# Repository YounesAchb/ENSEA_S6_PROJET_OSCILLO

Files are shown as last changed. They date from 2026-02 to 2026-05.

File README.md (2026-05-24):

# ENSEA S6 — Projet Oscilloscope Portable Connecté

Ce dépôt contient l'intégralité des sources (conception matérielle KiCad, firmware STM32 et application Java Android) du projet de fin de S6 réalisé à l'ENSEA. 

## 👥 Étudiants concernés
* **Yassine JABOU**
* **Younes ACHBAD**
* **Gabriel BOUDOUX D'HAUTEFEUILLE**
* **Gökay OZDEN**

---

## 📝 Abstract & Contexte de Fin de Projet
Le but de ce projet est de concevoir un système embarqué autonome agissant comme un oscilloscope de précision déporté. L'écosystème est divisé en deux parties principales :
1. **Un boîtier d'acquisition autonome :** Reçoit le signal analogique, adapte son amplitude, le numérise via un STM32L476RG et transmet les trames via un module Bluetooth HC-05.
2. **Une interface utilisateur (Display) :** Une application Android native développée en Java permettant la visualisation en temps réel, le contrôle des calibres, les mesures par curseurs et le traitement fréquentiel (FFT).

⚠️ **Statut Réel du Projet (Post-Soutenance) :** Suite à un retard de livraison critique de notre fournisseur sur le composant analogique central (l'amplificateur à gain programmable PGA849), le PCB final n'a pas pu être assemblé et soudé à temps pour les tests physiques. 
Cependant, l'ensemble du projet a été validé avec succès par une **approche de virtualisation et de simulation** :
* **Hardware :** PCB double couche entièrement routé et validé par DRC sous KiCad.
* **Firmware C :** 100% fonctionnel, validé sur carte Nucleo en simulant l'absence du PGA.
* **Application Android :** 100% fonctionnelle, dotée d'un banc de simulation générant des signaux virtuels cohérents permettant de valider l'interface utilisateur, le protocole de communication et les algorithmes de traitement (FFT, curseurs).

---

## 🛠 Spécifications du Projet

### 1. Performances & Objectifs Communs
* **Nombre d'entrées :** 2 voies (1 voie implémentée et validée sur cette version).
* **Bande passante visée :** 10 Hz - 50 kHz.
* **Résolution d'acquisition :** 12 bits.
* **Échantillonnage :** 10 kHz fixe, rythmé de manière matérielle par Timer.
* **Points par capture :** Buffer circulaire de 1024 points (gestion par demi-tableaux de 512 points).
* **Communication :** Liaison Bluetooth SPP (Standard Serial Port Profile) à 115200 bauds.
* **Gestion de l'énergie :** Objectif d'autonomie de 6 heures sur piles (sélection de composants Low-Power).

### 2. Architecture Matérielle (Hardware)

Le routage a été optimisé sur un PCB compact double couche. La conception repose sur une séparation stricte des masses et une cascade d'alimentation spécifique pour préserver la propreté du signal de référence ($V_{ref}$) de l'ADC.

#### Schéma Bloc de l'Architecture Électronique
```mermaid
graph TD
    classDef power fill:#2d3436,stroke:#deff9a,stroke-width:2px,color:#fff;
    classDef analog fill:#d63031,stroke:#fff,stroke-width:2px,color:#fff;
    classDef digital fill:#0984e3,stroke:#fff,stroke-width:2px,color:#fff;
    classDef com fill:#00b894,stroke:#fff,stroke-width:2px,color:#fff;

    subgraph Alimentation & Énergie
        Piles((Piles 3xAA)) -->|BAT_PLUS| Switch[Interrupteur + Diode Schottky]
        Switch -->|Vin| LDO3[LDO 3.3V: AP2112K]:::power
        Switch -->|Vin| LDO5[LDO 5V: MCP1826S]:::power
        LDO5 -->|Sortie 5V| Traco[DC/DC Symétrique: Traco TSM]:::power
        Traco -->|+15V / -15V| PGA
    end

    subgraph Chaîne Analogique
        BNC((BNC Verticale 50Ω)) -->|Signal Brut| PGA[Ampli de précision: PGA849]:::analog
        PGA -->|Signal Conditionné| Clamping[Diode de protection: BAT54S]:::analog
        Clamping -->|Entrée Analogique PA0| MCU
    end

    subgraph Traitement & Communication
        LDO3 -->|V3.3_DIG| MCU[MCU: STM32L476RG]:::digital
        MCU -->|Sélection Calibre 3-bits| PGA
        LDO5 -->|5V BT| BT[Module Bluetooth: HC-05]:::com
        MCU <-->|UART 115200 bauds| BT
        BT -.->|Sans-fil SPP| Android((App Android Java)):::com
    end

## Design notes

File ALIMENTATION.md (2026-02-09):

**Systeme d’alimentation** 

**Batterie Renata Li-Po 500mAh :**  source d'énergie. Compacte et fiable, elle offre environ 7 heures d'autonomie.  
**Régulateur LDO AP2112K (3,3V) :** convertit la tension variable de la batterie en un 3,3V stable pour le STM32. Il est choisi pour son faible bruit, indispensable pour ne pas perturber les mesures de l'oscilloscope.  
**Chargeur MCP73831 :** C'est le "cerveau" de la recharge. Il gère le cycle de charge sécurisé de la batterie (CC/CV) pour éviter toute surchauffe.  
**Connecteur USB-C GCT (USB4110) :** port d'entrée pour l'énergie. Il est robuste mécaniquement et possède des pins accessibles pour une soudure manuelle facilitée.  
**Boîtier JST PHR-2 femelle :** C'est la partie en plastique qui se fixe au bout des fils de ta batterie pour permettre un branchement propre sur la carte.  
**Commutateur ON/OFF Würth :** Un interrupteur physique robuste pour allumer ou éteindre ton appareil sans avoir à débrancher la batterie.  
**Transistor BSS84 (MOSFET P) :** Il assure une protection électronique contre l'inversion de polarité. Si la batterie est branchée à l'envers, il coupe instantanément le circuit sans perte de tension.  
**Perle de ferrite Murata :** Elle agit comme un filtre "anti-parasites" pour isoler l'alimentation de la partie mesure (ADC) des bruits générés par le Bluetooth.  
**L'Embase JST PH mâle (B2B-PH-K-S) :** C'est le connecteur que l’on soude sur le PCB. Sans lui, on ne peut pas brancher ton boîtier PHR-2.  
**Les Contacts à sertir JST (SPH-002T-P0.5L) :** Ce sont les petites broches métalliques qu'il faut fixer au bout des fils de la batterie avant de les glisser dans le boîtier PHR-2.

COMPOSANTS QUE JE N’AI PAS RAJOUTÉ AU SOURCING   
**1.Résistances de configuration**

* **2x Résistances de 5,1 kΩ :** À placer sur les pins CC1 et CC2 du port USB-C. Sans elles, les chargeurs modernes (smartphone/PC) ne délivreront aucun courant.  
* **1x Résistance de 2 kΩ :** À brancher sur la puce MCP73831 pour fixer le courant de charge à 500mA (recharge complète en 1h).  
* **2x Résistances de 100 kΩ :** Pour créer un "pont diviseur". Cela permet au STM32 de mesurer la tension de la batterie et d'envoyer le niveau de charge (ex: 75%) à ton smartphone et surtout faire un pont diviseur de tension pour limiter la tension de la batterie .  
* **1x Résistance de 470 Ω :** Pour limiter le courant de la LED de statut.

#### **2\. Condensateurs de stabilité**

* **2x Condensateurs de 10 µF (Céramique) :** Indispensables pour stabiliser l'entrée et la sortie du chargeur MCP73831.  
* **2x Condensateurs de 1 µF (Céramique) :** Nécessaires pour que le régulateur AP2112K fonctionne sans osciller.  
* **Plusieurs condensateurs de 100 nF :** À placer au plus près de chaque puce (STM32, AOP) pour filtrer les micro-parasites.

#### **3\. Indicateur visuel**

* **1x LED (Rouge ou Verte) :** Indispensable pour savoir visuellement si la batterie est en cours de chargement quand tu branches l'USB.

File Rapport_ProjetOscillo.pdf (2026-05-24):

ÉCOLE NATIONALE SUPÉRIEURE DE

L'ÉLECTRONIQUE ET DE SES APPLICATIONS

RAPPORT DE PROJET — SEMESTRE 6

# OSCILLOSCOPE PORTABLE CONNECTÉ

2025-2026

Étudiants :

JABOU Yassine · ACHBAD Younes BOUDOUX d'HAUTEFEUILLE Gabriel · OZDEN Gökay

Oscilloscope Portable Connecté — ENSEA S6 2025–2026

JABOU · ACHBAD · BOUDOUX d'HAUTEFEUILLE · OZDEN | 2

### Remerciements

Nous remercions nos encadrants de l'ENSEA pour leur accompagnement tout au long du
semestre, | et | particulièrement | pour | leur | compréhension | lors | des | difficultés
d'approvisionnement que nous avons rencontrées. Leurs retours lors des séances de suivi ont été déterminants pour prioriser nos efforts sur ce qui était réalisable dans les délais. Merci également au laboratoire de l'école pour l'accès au matériel de mesure et aux postes de soudure du FabLab

### Résumé

Ce rapport présente la conception et le développement d'un oscilloscope portable connecté, réalisé dans le cadre du projet de semestre 6 à l'ENSEA. Le projet s'articule autour d'un boîtier d'acquisition matériel (PCB sur STM32L476RG) et d'une application Android Java pour la visualisation des signaux via Bluetooth.
Note préliminaire sur l'état d'avancement : un retard critique de livraison de composants chez notre fournisseur principal (Mouser) a empêché l'assemblage final du PCB dans les délais du projet. Cette contrainte, indépendante de notre volonté, n'a pas remis en cause la conception — le routage KiCad est 100 % finalisé et validé (DRC OK) — mais elle a conduit à orienter la validation vers une approche simulation logicielle. L'ensemble du système est « ready-to-plug » : dès réception et soudure des composants manquants, la chaîne complète peut être mise en service sans modification de conception.
Ce qui a été pleinement développé et validé :
- PCB double couche ~24 × 95 mm : schéma complet, routage terminé, DRC validé, carte reçue du fabricant
- Firmware STM32 en C (HAL) : acquisition ADC 12 bits, DMA circulaire double buffer à 10 kHz, driver PGA849, protocole Bluetooth 0xAA/0x55, machine à états
- Application Android Java : affichage temps réel, trigger réglable, FFT 512 points (fenêtre de Hann), curseurs ΔT/ΔV, mesures automatiques, mode simulation complet
- Validation protocole complète : liaison UART/Bluetooth testée, endianness corrigé, trames vérifiées

Abstract

This report presents the design and development of a portable connected oscilloscope, completed as part of the semester 6 project at ENSEA. The system consists of a hardware acquisition board (PCB around STM32L476RG) and a Java Android application for wireless signal visualization over Bluetooth.
A critical component delivery delay prevented final PCB assembly within the project timeline. The KiCad routing is fully complete and DRC-validated; the system is ready-to-plug pending soldering. All software components — STM32 firmware (C, HAL, DMA), Bluetooth protocol, and the Android application (real-time display, FFT, trigger, cursors, simulation mode) — have been fully developed and validated through software simulation and partial hardware testing.

### 1. Introduction

### 1.1 Contexte et motivation

L'oscilloscope est l'instrument de base de tout laboratoire d'électronique. Il permet de visualiser en temps réel l'évolution d'un signal, de mesurer son amplitude et sa fréquence, et de diagnostiquer le comportement d'un circuit. Les oscilloscopes de banc professionnels sont efficaces mais encombrants et coûteux — souvent hors de portée pour un usage nomade ou terrain.
Ce projet visait à concevoir une alternative compacte : un oscilloscope embarqué alimenté sur batterie, qui transmet les données à un smartphone Android via Bluetooth. Toute la puissance d'affichage et de traitement du signal est déportée sur l'application mobile, ce qui simplifie le firmware et permet une interface bien plus riche qu'un écran embarqué de quelques centimètres.

### 1.2 Cahier des charges

Les spécifications fixées en début de projet étaient les suivantes :
- 2 voies d'entrée analogiques (1 voie implémentée dans la V1)
- Bande passante : 10 Hz – 50 kHz
- 1024 points par capture en mode dual, 2048 en mode simple
- Transmission Bluetooth sans dégradation vers application Android
- Autonomie visée : 6 heures sur batterie
- Interface de visualisation complète sur smartphone

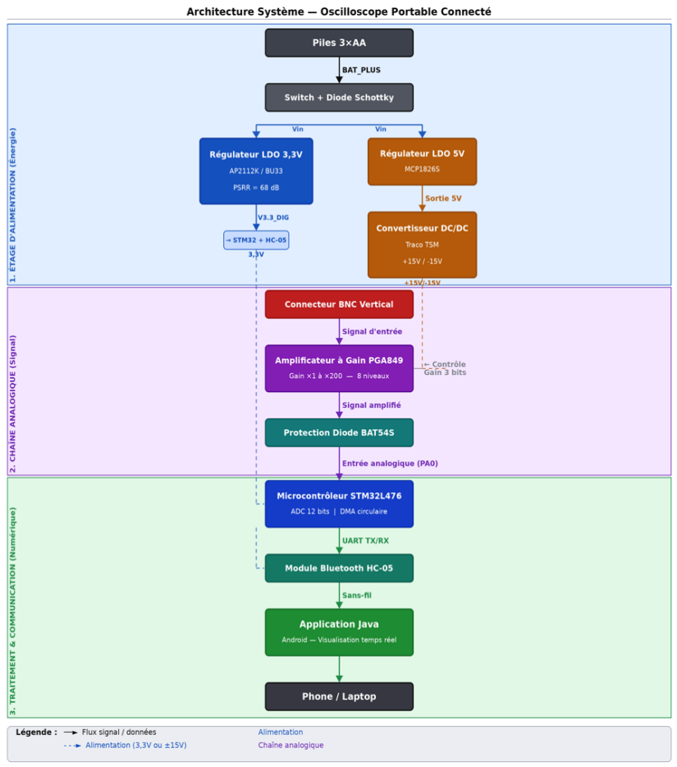
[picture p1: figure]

- Fig. 1 — Architecture globale du système : BNC → PGA849 → STM32 → HC-05 → Application Android Java.

### 1.3 Déroulement réel du projet et état final

Le projet a été conduit sur environ quatre mois, entre les contraintes académiques habituelles (cours, partiels) et les aléas propres à tout projet hardware : délais fournisseurs, itérations sur le schéma, débogage firmware. La chronologie réelle s'est articulée autour de trois phases :
1. Phase de conception (semaines 1–5) : spécifications, choix des composants, schéma KiCad, création des empreintes personnalisées (PGA849 QFN-16, TSM0515D).
2. Phase de développement logiciel (semaines 4–10) : firmware STM32 en parallèle du PCB, développement de l'application Android Java avec mode simulation.
3. Phase d'intégration (semaines 11–14) : routage PCB finalisé, DRC validé, carte envoyée en fabrication. Validation firmware + Bluetooth sur Nucleo. Assemblage PCB non finalisé (retard composants Mouser).

### 2. Présentation Générale du Projet

### 2.1 Architecture système

Le système se découpe en deux sous-ensembles communiquant sans fil :
- Le boîtier embarqué : chaîne analogique (BNC → PGA849 → ADC) + STM32 (firmware C, DMA, Bluetooth UART) + alimentation batterie.
- L'application Android Java : réception Bluetooth, décodage protocole, affichage temps réel, traitement signal (FFT, trigger, curseurs), simulation intégrée.

L'idée de déporter l'affichage sur le smartphone a été validée dès le départ. Cela évite d'intégrer un écran dans le boîtier, réduit la consommation, simplifie le firmware, et offre une interface incomparablement plus riche qu'un petit OLED.

### 2.2 Synthèse des choix techniques

Composant / Choix | Justification technique
STM32L476RG (NUCLEO) | ADC 12 bits intégré, famille L4 basse consommation, HAL documentée, familier des TPs
PGA849 (Texas Instruments) | Gain programmable 3 bits (×1 à ×200), faible bruit, piloté par 3 GPIO STM32
BU33SD5WG (ROHM, SSOP-5) | LDO 3,3 V, PSRR = 68 dB — filtre le ripple HF du Traco pour protéger l'ADC
TSM0515D (Traco Power) | Convertisseur DC/DC ±15 V isolé depuis 5 V pour alimentation symétrique PGA849
BAT54S (Schottky) | Double protection : inversion polarité batterie + clamping surtension entrée ADC
HC-05 Bluetooth SPP | UART transparent, profil SPP, simple à interfacer STM32 et Android
DMA Circulaire double buffer | Acquisition déterministe 10 kHz, zéro perte, charge CPU ≈ 0 % pendant l'ADC

Application Android Java | Interface riche (FFT, trigger, curseurs), mode simulation intégré, pas d'écran embarqué

### 3. Partie Hardware

### 3.1 État d'avancement — rappel de contexte

Les sections qui suivent décrivent la conception telle qu'elle a été réalisée. Les justifications techniques sont celles qui ont guidé les choix. Les résultats expérimentaux présentés en section 6 correspondent uniquement à ce qui a effectivement pu être testé.

### 3.2 Alimentation — Conception de la chaîne d'énergie

### 3.2.1 Contraintes et architecture

La chaîne d'alimentation est le sous-système qui a demandé le plus de réflexion, pour deux raisons :
- Le PGA849 nécessite une alimentation symétrique (±VS) pour amplifier des signaux centrés autour de 0 V sans saturation.
- L'ADC 12 bits de la STM32 a une résolution de 1 LSB = 3300/4096 ≈ 0,806 mV. La moindre perturbation haute fréquence sur la tension d'alimentation se retrouve directement dans les échantillons numérisés.

Ces deux contraintes ont conduit à une architecture cascade à deux branches, illustrée ci-dessous :

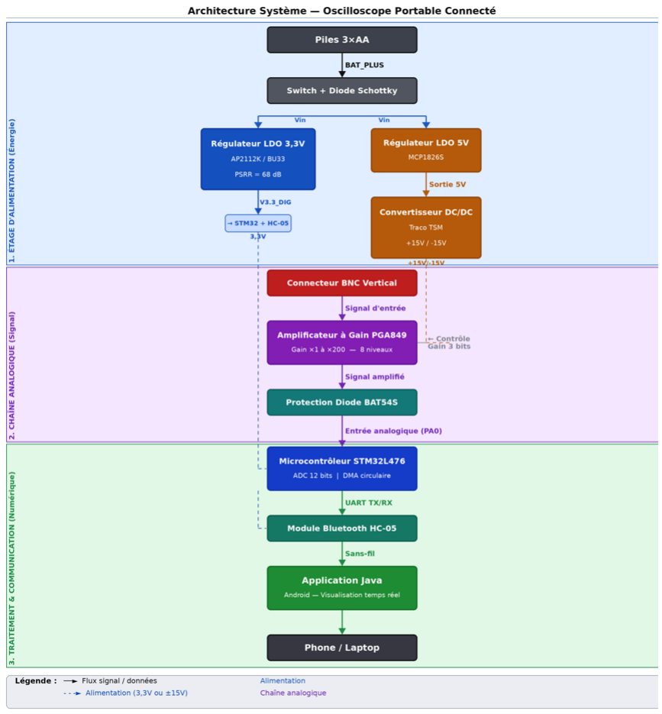
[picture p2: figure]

Fig. 1 — Architecture globale du système : BNC → PGA849 → STM32 → HC-05 → Application Android Java.

### 3.2.2 Branche 1 — Alimentation ±15 V pour le PGA849

Les piles 3×AA (4,5 V nominal) alimentent d'abord un LDO MCP1826S qui fournit un 5 V stabilisé. Ce 5 V est ensuite converti en ±15 V symétrique par le TSM0515D de Traco Power, un convertisseur DC/DC isolé à découpage.
Le TSM0515D est un module tout-intégré qui simplifie considérablement la conception : pas besoin de transformer, de contrôleur PWM, ni de bobine externe. Il génère cependant un ripple HF caractéristique des convertisseurs à découpage — ce qui impose le soin apporté à la branche 3,3 V.

### 3.2.3 Branche 2 — 3,3 V propre pour le STM32 : le rôle clé du BU33SD5WG

La branche 3,3 V est critique. Elle alimente directement le STM32 (donc son ADC) et le module Bluetooth. Pour cette branche, nous avons sélectionné le LDO BU33SD5WG de ROHM (boîtier SSOP-5, 500 mA max) à la place d'un LDO générique.
Le critère déterminant est son PSRR (Power Supply Rejection Ratio) exceptionnel de 68 dB. Ce paramètre mesure la capacité du régulateur à atténuer les perturbations présentes sur sa tension d'entrée avant qu'elles n'atteignent la sortie. En termes concrets :
PSRR = 68 dB → atténuation = 10^(68/20) ≈ 2512×
Autrement dit, un bruit de 100 mV crête sur l'entrée du BU33SD5WG (généré par le Traco) n'apparaît qu'à ~40 µV sur la tension 3,3 V fournie à l'ADC. Or à 12 bits, 1 LSB = 0,806 mV : cette perturbation résiduelle de 40 µV représente moins de 0,05 LSB, ce qui est parfaitement négligeable. Un LDO standard (PSRR typique 40 dB) aurait laissé passer ~1 mV, soit plus d'un LSB de bruit parasite.
Ce choix est donc la clé de la précision de mesure du système, et pas un détail de conception.

### 3.2.4 Protection en entrée — Diode Schottky et BAT54S

Deux protections sont intégrées en entrée du circuit :
- Diode Schottky série : protège l'ensemble du circuit contre une inversion de polarité lors de l'insertion des piles. Le seuil bas (~0,3 V) minimise la chute de tension sur la branche d'alimentation.
- BAT54S (double Schottky en boîtier SOT-23) : utilisée comme diode de clamping sur l'entrée analogique. En cas de signal d'entrée dépassant les rails d'alimentation du PGA, les diodes Schottky écrêtent la tension avant qu'elle n'atteigne l'ADC. Les diodes Schottky sont privilégiées ici pour leur faible capacité parasite, qui n'altère pas la bande passante du signal.
Composant | Référence | Rôle | Valeur clé
LDO 5 V | MCP1826S | 5 V stabilisé pour le Traco | 1 A max
DC/DC ±15 V | TSM0515D (Traco) | Alimentation symétrique PGA849 | Isolé, ±15 V / 70 mA
LDO 3,3 V | BU33SD5WG (ROHM) | 3,3 V propre STM32 + HC-05 | PSRR = 68 dB
Découplage HF | 100 nF × 10 (CMS) | Filtrage hautes fréquences | Placés au plus près des ICs
Filtrage BF | 10 µF × 3 (électro) | Stabilisation basse fréquence | Sorties régulateurs
Protection polarité | Schottky série | Inversion polarité batterie | Vf ≈ 0,3 V
Protection ADC | BAT54S | Clamping surtension entrée | Faible capacité parasite

### 3.2.5 Estimation d'autonomie

Avec 3 piles AA de 2500 mAh et une consommation totale estimée à ~400 mA (STM32 ~30 mA, PGA849 ~10 mA, HC-05 ~40 mA, TSM0515D ~100 mA équivalent avec pertes) : Autonomie estimée ≈ 2500 mAh / 400 mA ≈ 6,25 heures
Cette valeur est cohérente avec l'objectif du cahier des charges (6 heures). Elle n'a pas pu être vérifiée expérimentalement faute d'avoir assemblé le circuit complet.

### 3.3 Chaîne d'acquisition analogique

### 3.3.1 Amplificateur à gain programmable PGA849

Le PGA849 de Texas Instruments est l'élément central de la chaîne d'acquisition. Il amplifie le signal d'entrée avec un gain sélectionnable sur 8 niveaux, codés en binaire sur 3 broches logiques (A0, A1, A2) pilotées par les GPIO PA4, PA5, PA6 de la STM32.
Le signal d'entrée arrive via un connecteur BNC vertical (TE Connectivity 1478204), standard en laboratoire. La sortie du PGA attaque directement l'entrée analogique de l'ADC1 (broche PA0, canal IN5 de la STM32).
Code A2:A1:A0 | Gain | Plage d'entrée typique
000 | ×1 | > 1 V crête — signaux forts
001 | ×2 | 500 mV – 1 V
010 | ×5 | 200 – 500 mV
011 | ×10 | 100 – 200 mV
100 | ×20 | 50 – 100 mV
101 | ×50 | 20 – 50 mV
110 | ×100 | 10 – 20 mV
111 | ×200 | < 10 mV — signaux très faibles

### 3.3.2 Résolution de l'ADC

L'ADC1 de la STM32L476 est configuré en 12 bits, référence Vref = 3,3 V :

### 1 LSB = 3300 mV / 4096 ≈ 0,806 mV (gain ×1)

Au gain maximum ×200 du PGA, la résolution effective sur le signal d'entrée descend à 0,806 / 200 ≈ 4 µV/bit en théorie. En pratique, le bruit de fond du PGA849 et du câble d'entrée fixerait la résolution réelle à quelques dizaines de µV — ce qui reste excellent pour la plage de fréquences visée.

### 3.4 PCB — Conception et routage

### 3.4.1 Caractéristiques

Format double couche, dimensions ~24 × 95 mm, coins arrondis. Organisation des couches :
- F.Cu : signaux, pistes 0,25 mm minimum, composants CMS (STM32 LQFP-64, PGA849 QFN-16, Traco TSM0515D, LDO, condensateurs)
- B.Cu : plan de masse GND continu (copper fill) — isole les perturbations HF du Traco et garantit un retour de courant propre

Connectique intégrée : BNC vertical THT (entrée signal), module HC-05 (Bluetooth), connecteur SWD 5 broches J4 (SWCLK, SWDIO, NRST, GND, 3,3 V) pour programmation et debug sans démonter la carte, interrupteur glissière marche/arrêt, support piles 3×AA, 2 vis M3 pour fixation boîtier.

### 3.4.2 Règles de routage appliquées

- Isolation analogique : BNC et PGA849 regroupés, distants des zones numériques (STM32, HC-05). Le plan de masse continu B.Cu sépare physiquement les domaines.
- Découplage au plus près : les 100 nF sont placés à moins de 2 mm de chaque broche d'alimentation des ICs.
- Empreintes personnalisées : PGA849 QFN-16 et TSM0515D créées manuellement dans la librairie Empreintes.pretty — les bibliothèques standard KiCad ne les incluent pas.
- DRC validé sans erreur — la carte a été envoyée en fabrication et reçue.

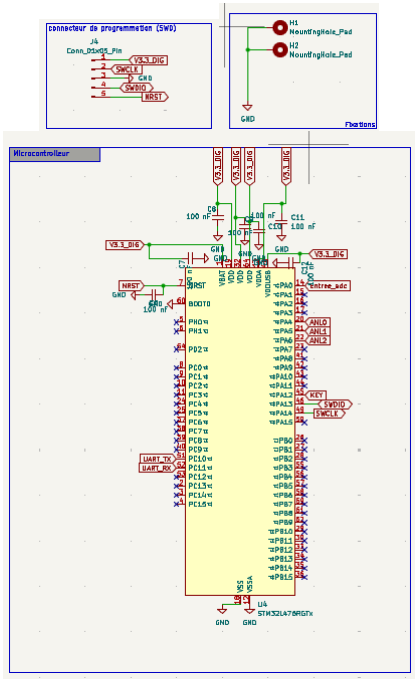
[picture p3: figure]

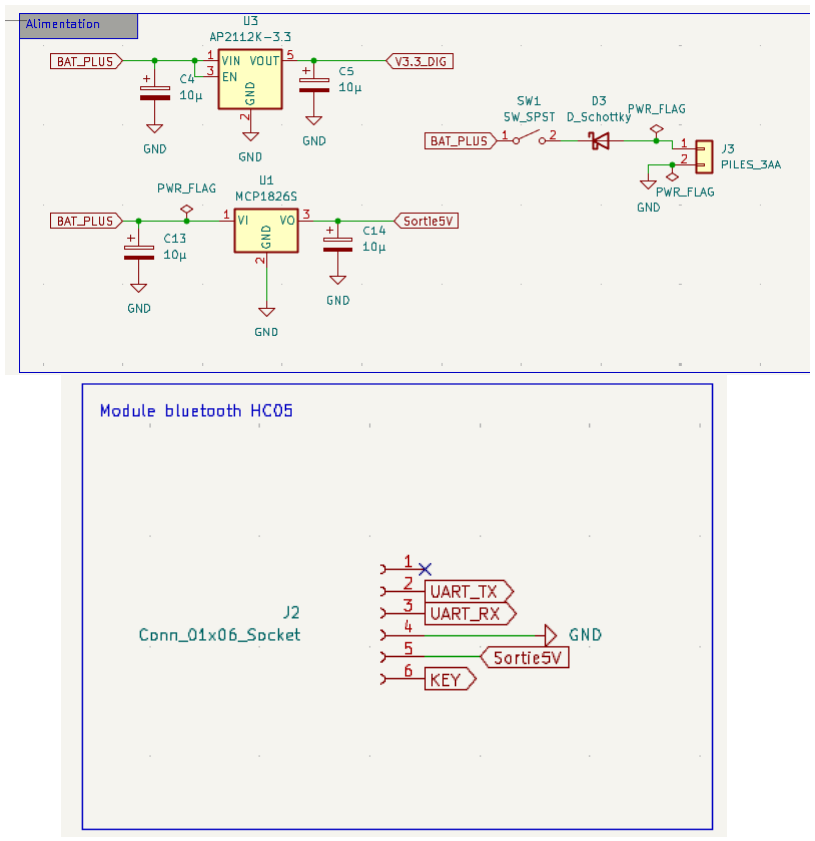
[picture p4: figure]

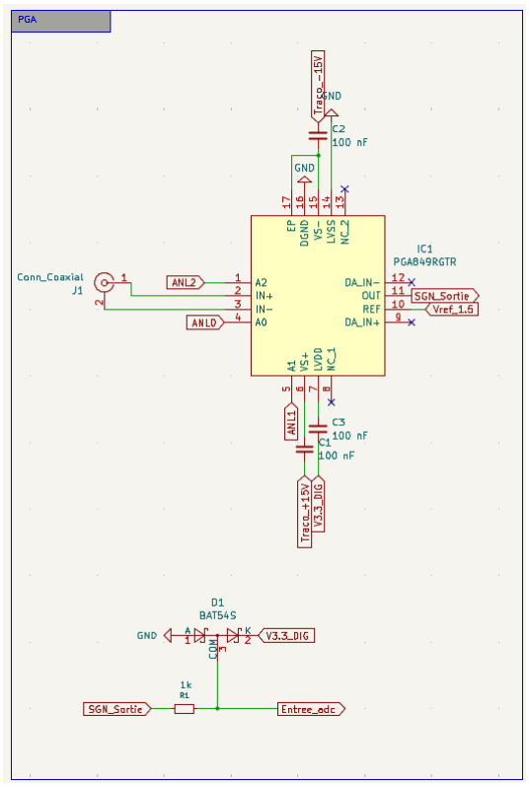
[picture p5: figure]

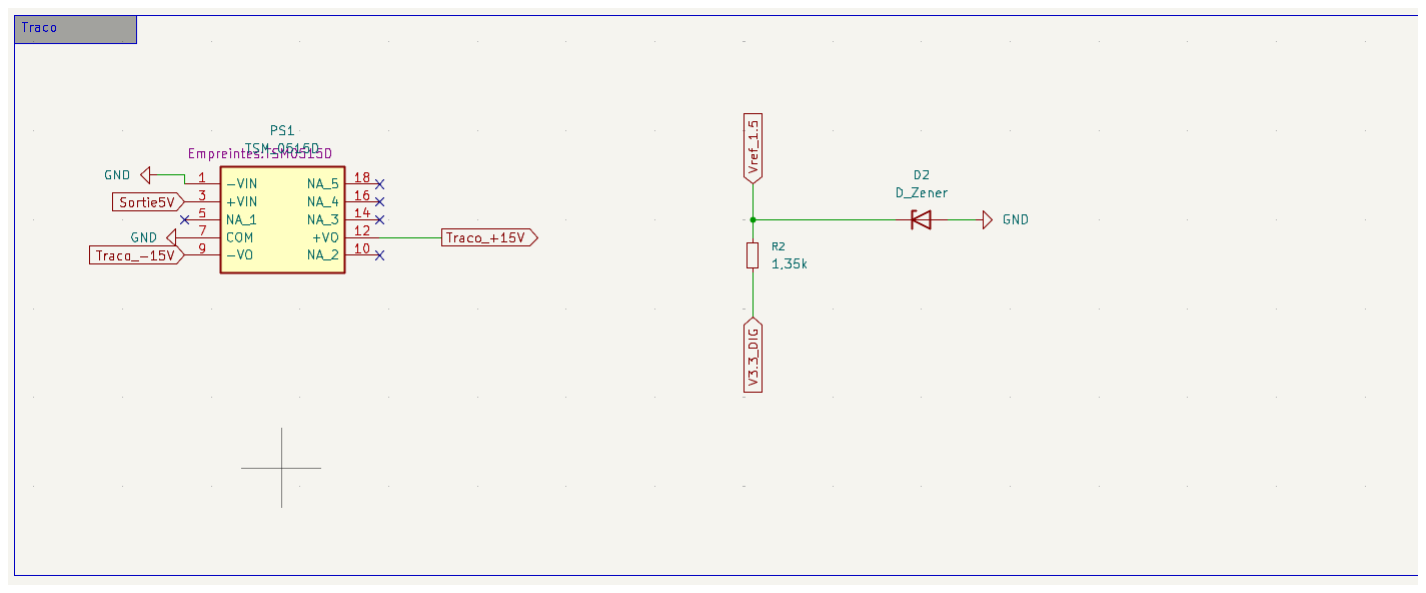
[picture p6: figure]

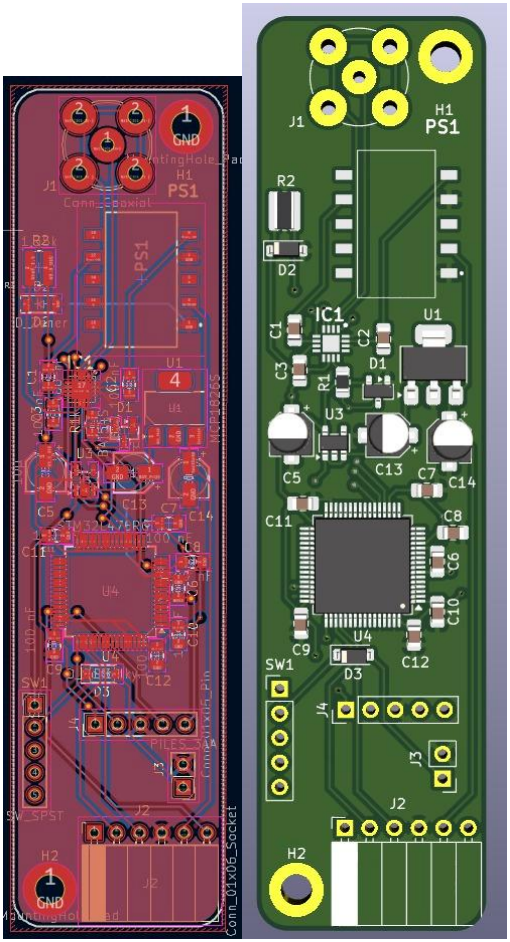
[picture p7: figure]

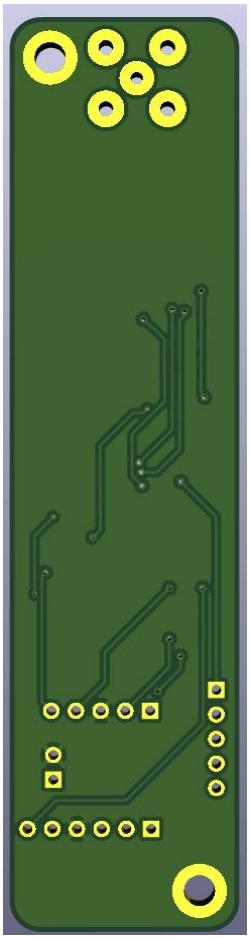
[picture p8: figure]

Fig. 2 — Schematic et PCB routé sous KiCad (vue F.Cu). Format ~24×95 mm, double couche. DRC validé.

### 4. Firmware STM32 — Architecture et Déterminisme

### 4.1 Vue d'ensemble

Le firmware est développé en C avec la HAL STM32 (configurée via STM32CubeMX 6.15.0). Il est organisé en modules fonctionnels indépendants, ce qui a facilité le développement en équipe et le débogage par sous-système. Les modules principaux :

Module | Rôle
main.c | Machine à états, boucle principale, orchestration
acquisition.c/.h | ADC1 + TIM2 + DMA circulaire double buffer
pga849.c/.h | Driver PGA849 — contrôle gain via GPIO PA4/5/6
protocol.c/.h | Construction/parsing trames Bluetooth (0xAA/0x55 + checksum XOR)
uart_handler.c/.h | Gestionnaire UART HC-05 — TX DMA, RX interruption, file commandes
freq_measure.c/.h | Estimation fréquence par zero-crossing (méthode logicielle)
freq_hw.c/.h | Mesure fréquence hardware via TIM3 Input Capture (PB4, AF2)

### 4.2 Machine à états

Le firmware suit une machine à états à trois niveaux : SYSTEM_INIT → IDLE → ACQUISITION. Cette structuration garantit que le système ne démarre jamais l'ADC avant que tous les périphériques soient correctement initialisés, et permet de gérer proprement les transitions pause/reprise commandées par Bluetooth.

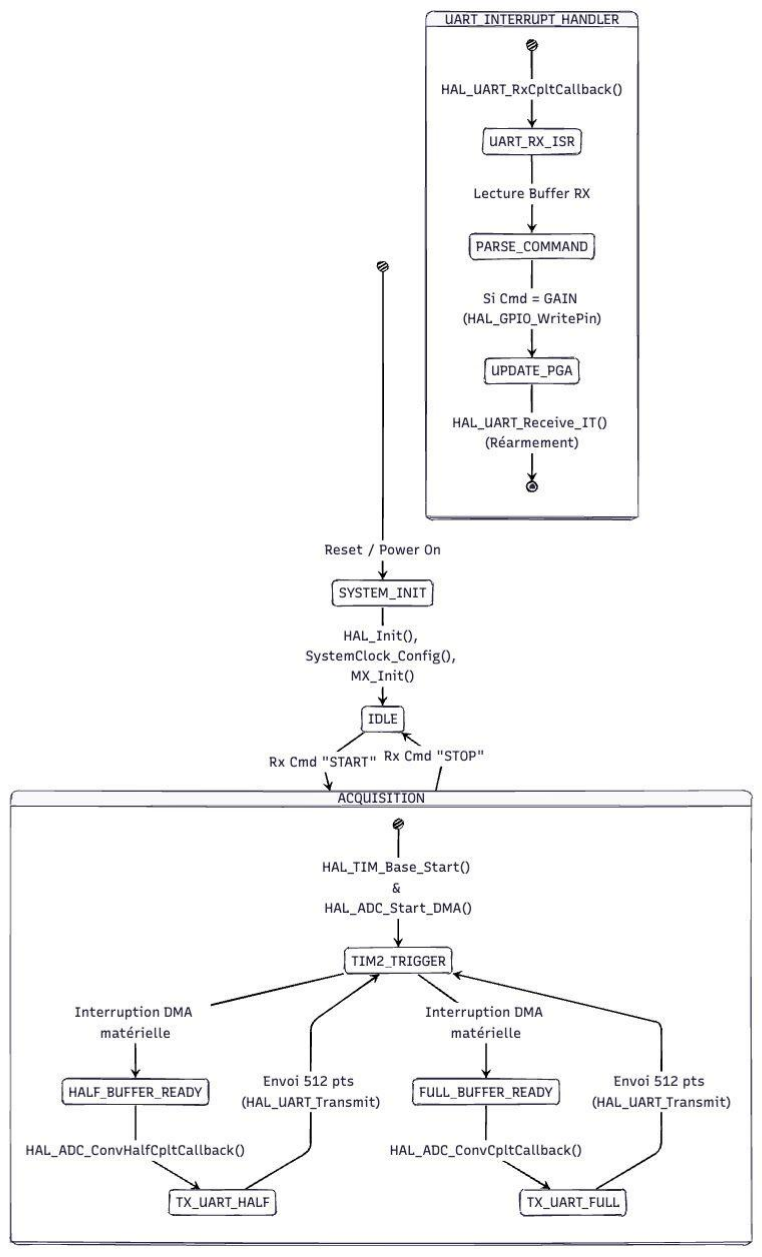
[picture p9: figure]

Fig. 3 — Machine à états du firmware STM32. SYSTEM_INIT → IDLE → ACQUISITION DMA, piloté par interruptions TIM2.

### 4.3 Acquisition ADC — DMA Circulaire Double Buffer

### 4.3.1 Principe et déterminisme

L'acquisition est le sous-système le plus critique en termes de déterminisme. L'objectif est d'échantillonner le signal à exactement 10 kHz, sans aucune perte d'échantillon, tout en permettant au CPU de traiter et transmettre les données en parallèle.
La solution retenue repose sur trois mécanismes combinés :

4. TIM2 génère un événement UPDATE à 10 kHz (SYSCLK=80 MHz, PSC=7, ARR=999), qui déclenche directement l'ADC via TRGO — le timing est matériel, parfaitement régulier, indépendant du CPU.
5. L'ADC dépose chaque résultat en RAM via DMA1 (mode circulaire) — aucune intervention CPU pendant les conversions.
6. Le buffer DMA de 1024 samples est divisé en deux moitiés : pendant que le CPU traite la première moitié, le DMA remplit la seconde, puis les rôles s'inversent.

Ce mécanisme de double buffering garantit deux propriétés essentielles : zéro perte d'échantillon (le flux ADC n'est jamais interrompu) et charge CPU ≈ 0 % pendant l'acquisition (le DMA travaille de manière totalement autonome).

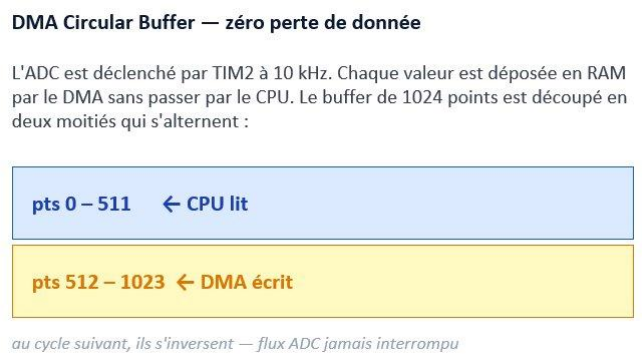
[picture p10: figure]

DMA Circular Buffer — double buffering. Les deux moitiés s'alternent : flux ADC jamais interrompu, zéro perte d'échantillon.

### 4.3.2 Implémentation — Callbacks HAL et synchronisation

Les deux callbacks HAL signalent la disponibilité de chaque moitié. Un flag volatile ACQ_Status_t est mis à jour dans l'ISR, puis consommé par la boucle principale :

// acquisition.c — callbacks DMA ISR (interruptions)
void HAL_ADC_ConvHalfCpltCallback(ADC_HandleTypeDef *hadc) { if (hadc->Instance == ADC1)
acq_status = ACQ_HALF_READY; // samples[0..511] prêts }
void HAL_ADC_ConvCpltCallback(ADC_HandleTypeDef *hadc) { if (hadc->Instance == ADC1)
acq_status = ACQ_FULL_READY; // samples[512..1023] prêts }

// main.c — boucle principale (poll du flag, non bloquant) ACQ_Status_t status = ACQ_GetStatus();
if (status != ACQ_NONE) {
const uint16_t *half = ACQ_GetReadyHalf();
ACQ_ClearStatus(); | // ← AVANT le traitement (ordre critique !)
if (half != NULL && app_running) {
// Calcul min / max / moyenne sur 512 samples

// Estimation fréquence (zero-crossing ou TIM3 IC) // Envoi trame Bluetooth si TX DMA libre
}
}

L'ordre d'appel de ACQ_ClearStatus() est fondamental : il doit précéder le traitement des données. Si le flag est effacé après, la boucle peut ignorer un callback DMA qui survient pendant le traitement, et la fréquence effective d'acquisition chute de moitié. Ce bug a été découvert et corrigé lors des tests sur Nucleo (voir section 7.2).

### 4.4 Protocole Bluetooth — Trame et Endianness

### 4.4.1 Structure de la trame

Chaque demi-trame de 512 samples est encapsulée dans un paquet binaire avec checksum XOR pour la détection d'erreurs :

Champ | Taille | Valeur / Description
Header 1 | 1 octet | 0xAA — marqueur de début
Header 2 | 1 octet | 0x55 — marqueur de synchronisation
CMD | 1 octet | 0x01 = DATA, 0x02 = ACK, 0x03 = SYSINFO
LEN | 2 octets | Longueur payload en big-endian
PAYLOAD | 1024 octets | 512 samples × 2 octets, encodés big-endian
CHECKSUM | 1 octet | XOR de tous les octets depuis CMD inclus

Taille totale d'une trame DATA : 1030 octets. À 115 200 bps, la durée d'émission est d'environ 90 ms, ce qui laisse 51,2 ms de marge par rapport à la période de la demi-trame (~51,2 ms à 10 kHz / 512 samples). Le débit est donc au limit — le flag tx_busy dans uart_handler.c garantit qu'on ne lance pas un nouvel envoi DMA avant que le précédent ne soit terminé.

### 4.4.2 Problème d'Endianness — diagnostic et correction

Un bug non trivial a été découvert lors des premiers tests de communication : l'application Android affichait des valeurs complètement incohérentes alors que le firmware envoyait des données visiblement correctes côté STM32.
La cause : l'architecture ARM Cortex-M4 du STM32 est nativement little-endian — les octets d'un uint16_t sont stockés dans l'ordre LSB d'abord, MSB ensuite. Or Java (et la JVM Android) traite les types multi-octets en big-endian : MSB d'abord. Un sample de valeur 0x0C00 (3072 en décimal, ~2,4 V) était donc interprété par l'application comme 0x000C (12 en décimal, ~10 mV).
La correction a été appliquée dans PROTO_BuildDataFrame() : chaque sample uint16_t est explicitement inversé octet par octet avant d'être écrit dans le buffer de transmission :

// protocol.c — inversion Endianness à l'encodage
for (uint16_t i = 0; i < nb_samples; i++) {
tx_buf[idx++] = (uint8_t)(samples[i] >> 8); | // MSB en premier (big-
endian)

tx_buf[idx++] = (uint8_t)(samples[i] & 0xFF); // LSB ensuite
// → Java lit naturellement : (buf[0] << 8) | buf[1] = valeur correcte
}

Ce bug illustre bien une difficulté classique des systèmes embarqués hétérogènes : l'interopérabilité entre architectures little-endian et big-endian nécessite une gestion explicite à chaque frontière de sérialisation.

### 4.4.3 Commandes Android → STM32

Les commandes depuis le téléphone vers le firmware sont encodées sur un seul octet ASCII, ce qui simplifie le parseur et évite de gérer une machine à états de parsing côté STM32 :

// protocol.h — commandes RX (un seul octet ASCII)
#define PROTO_RX_GAIN_MIN | '0' | // codes '0'..'7' = changement gain PGA

#define PROTO_RX_GAIN_MAX | '7'

#define PROTO_RX_SYSINFO | 'S' | // demande infos système (Fs, gain, Vref)

#define PROTO_RX_PAUSE | 'P' | // pause acquisition (TIM2 stop)

#define PROTO_RX_RESUME | 'R' | // reprise acquisition (TIM2 start)

### 4.5 Driver PGA849 — Contrôle gain

Le driver est volontairement minimal. Il écrit 3 bits GPIO en sortie push-pull et maintient un lookup table statique pour la conversion code → multiplicateur réel :

// pga849.c — table de correspondance et contrôle GPIO
static const uint16_t lut[8] = { 1, 2, 5, 10, 20, 50, 100, 200 };

void PGA_SetGain(PGA_Gain_t gain) {
gain &= 0x07;
HAL_GPIO_WritePin(PGA_A0_GPIO_Port, PGA_A0_Pin, (gain & 0x01) ? GPIO_PIN_SET : GPIO_PIN_RESET); HAL_GPIO_WritePin(PGA_A1_GPIO_Port, PGA_A1_Pin, (gain & 0x02) ? GPIO_PIN_SET : GPIO_PIN_RESET); HAL_GPIO_WritePin(PGA_A2_GPIO_Port, PGA_A2_Pin, (gain & 0x04) ? GPIO_PIN_SET : GPIO_PIN_RESET); current_gain = gain;
}

Le changement de gain est sécurisé : ACQ_Suspend() stoppe TIM2, le nouveau gain est appliqué, un délai de settling d'1 ms est respecté (selon la datasheet PGA849), puis ACQ_Resume() relance TIM2. Un ACK est envoyé à l'application pour confirmation.

### 4.6 Estimation de fréquence

### 4.6.1 Méthode logicielle — Zero-crossing

La fréquence est estimée par comptage de fronts montants dans la demi-trame de 512 samples. L'algorithme calcule la moyenne du buffer (référence DC locale), compte les passages de en-dessous vers au-dessus, et en déduit :
f = Fs × N_crossings / N_samples = 10000 × N / 512

Cette méthode est suffisante pour des signaux périodiques propres entre ~20 Hz et 4 kHz. Elle dégrade au-delà (approche de Nyquist) et pour les signaux très bruités.

### 4.6.2 Méthode hardware — TIM3 Input Capture

Une méthode plus précise est disponible via freq_hw.c : le TIM3 est configuré en Input Capture sur PB4 (AF2, 1 MHz de résolution avec PSC=79). La période entre deux fronts montants consécutifs est mesurée avec une résolution de 1 µs. Cette méthode est prioritaire si elle retourne une valeur non nulle — elle nécessite un signal numérique mis en forme sur PB4, ce qui n'est pas implémenté dans le PCB V1 mais est prévu pour la V2.

### 5. Application Android Java

### 5.1 Présentation et rôle dans le projet

L'application Android est le composant le plus abouti du projet. Développée en Java natif Android (AppCompatActivity), elle offre une interface d'oscilloscope complète : affichage temps réel, trigger, FFT, curseurs, mesures automatiques. Elle intègre également un mode simulation qui génère des signaux synthétiques en interne, ce qui a servi de banc de test logiciel pendant tout le développement, en l'absence de hardware complet.

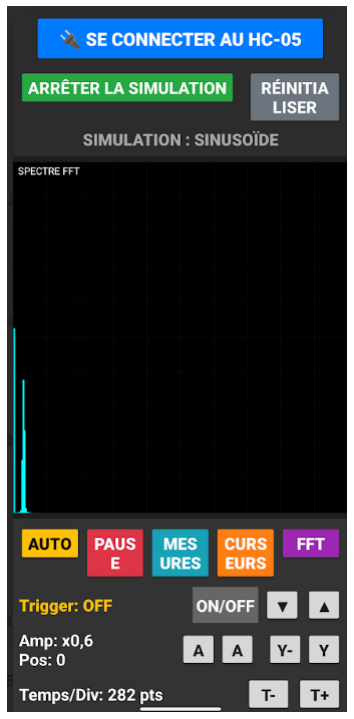
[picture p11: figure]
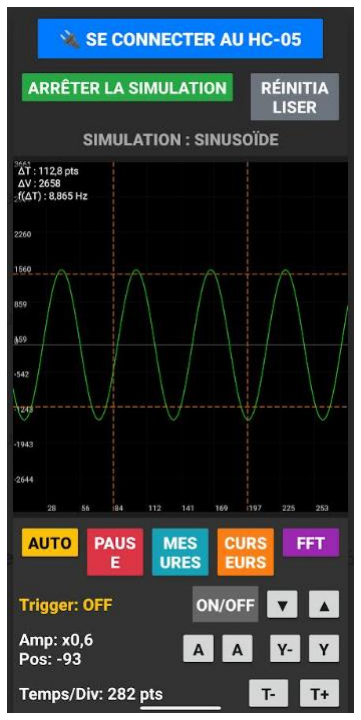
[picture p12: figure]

Fig. 5 — Application Android (mode simulation). Affichage temps réel, contrôles gain/trigger/FFT.

### 5.2 Architecture — Diagramme de classes

L'application repose sur deux classes principales qui communiquent via l'interface OnValuesChangeListener :

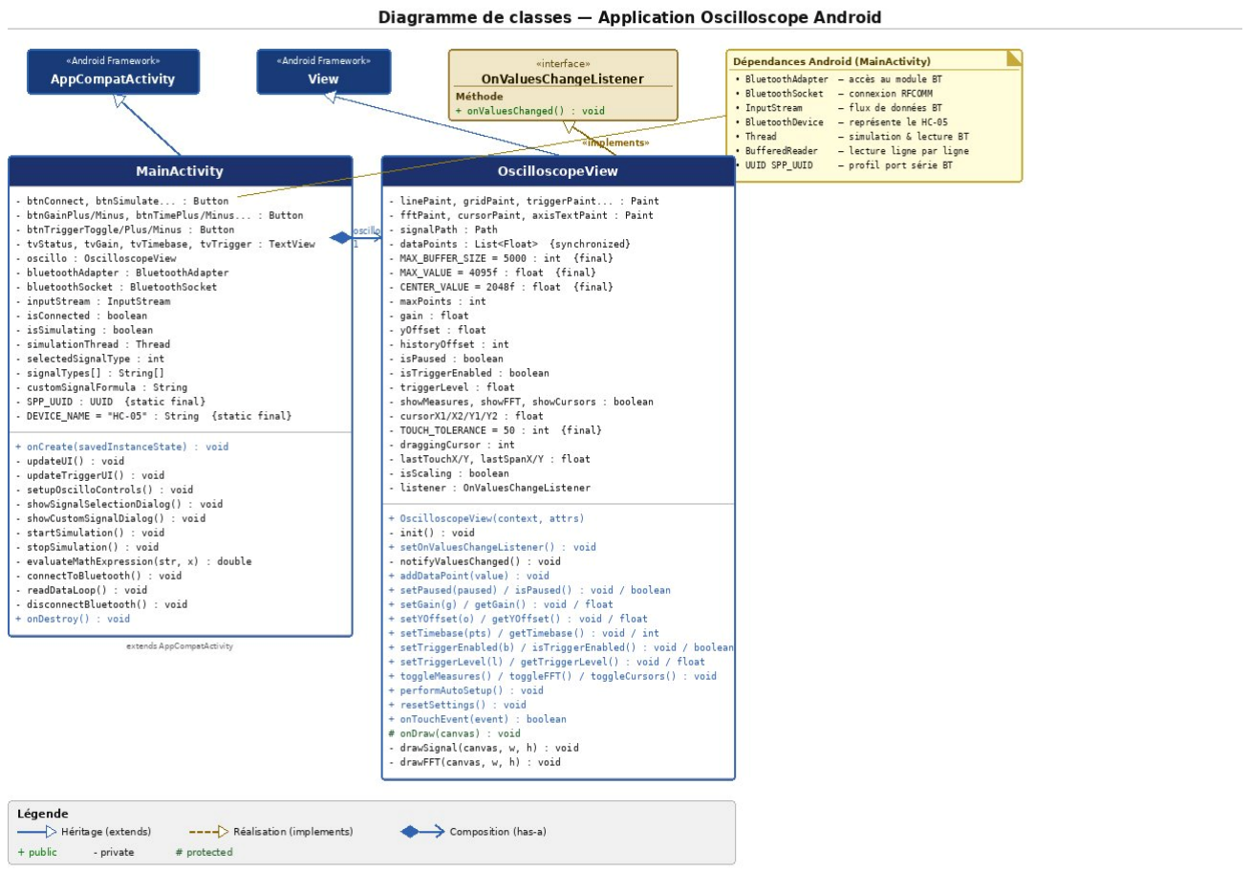
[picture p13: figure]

Fig. 4 — Diagramme de classes Java. MainActivity ↔ OscilloscopeView via OnValuesChangeListener.

### 5.2.1 MainActivity

MainActivity étend AppCompatActivity et orchestre l'ensemble de l'application. Ses responsabilités :
- Connexion Bluetooth RFCOMM au HC-05 (UUID SPP : 00001101-0000-1000-8000-00805F9B34FB)
- Lecture continue de l'InputStream Bluetooth dans un Thread dédié (readDataLoop)
- Mode simulation : un simulationThread génère des signaux synthétiques à fréquence et amplitude configurables
- Contrôles UI : boutons Connect/Simulate, réglages gain/timebase/trigger, toggles FFT/curseurs/mesures
- Gestion des signaux personnalisés : evaluateMathExpression() permet d'entrer une formule mathématique (sin(x)+0.5*cos(3*x), etc.)

### 5.2.2 OscilloscopeView

OscilloscopeView étend View et réalise l'intégralité du rendu graphique et du traitement du signal. C'est le composant le plus complexe de l'application. Attributs principaux :
- dataPoints (List<Float>, synchronisé) : buffer circulaire des données, MAX_BUFFER_SIZE = 5000 points
- gain, yOffset : mise à l'échelle verticale et décalage

- timebase : nombre de points affichés horizontalement (zoom temporel)
- triggerLevel, isTriggerEnabled : paramètres du trigger
- showFFT, showMeasures, showCursors : toggles des affichages supplémentaires
- cursorX1/X2/Y1/Y2 : positions des 4 curseurs déplaçables

### 5.3 Fonctionnalités

### 5.3.1 Affichage et trigger

La méthode onDraw(Canvas) trace le signal via Canvas.drawPath(). Le trigger est implémenté par recherche du premier front montant dépassant triggerLevel — même principe que le firmware, ce qui garantit une cohérence entre les deux représentations. L'utilisateur règle le seuil depuis l'interface (+/− par pas de 100 unités sur l'échelle 0–4095).

### 5.3.2 Zoom et navigation tactile

onTouchEvent() gère deux gestes : pinch à deux doigts (zoom horizontal timebase et vertical gain, via distance inter-doigts entre ACTION_MOVE) et glissement à un doigt (navigation historique historyOffset et décalage vertical yOffset). La détection du passage pinch ↔ glissement se fait sur isScaling.

### 5.3.3 Analyse FFT

L'application intègre une FFT de 512 points (algorithme de Cooley-Tukey Decimation-In-Time, implémenté en Java). Une fenêtre de Hann est appliquée avant le calcul pour réduire les lobes secondaires. Le spectre est affiché en barres verticales dans la partie basse de l'écran, en temps réel. Ce module a été validé en simulation : un sinus à 1 kHz (Fs = 10 kHz simulé) produit bien un pic spectral unique à la bonne fréquence.

### 5.3.4 Mesures automatiques — performAutoSetup()

La méthode performAutoSetup() analyse les 2000 derniers points pour calculer Vmax, Vmin, Vmoy, période par zero-crossing, puis ajuste automatiquement gain, yOffset et triggerLevel pour centrer le signal à l'écran. C'est l'équivalent du bouton « Auto » d'un oscilloscope classique. En mode mesures actif, l'application affiche en continu Vmax, Vmin, Vcc = Vmax − Vmin et la fréquence estimée.

### 5.3.5 Curseurs ΔT / ΔV

4 curseurs déplaçables par toucher (2 en X, 2 en Y) affichent en temps réel : ΔT = |X2 − X1| / Fs, ΔV = |Y2 − Y1| mis à l'échelle, et f = 1/ΔT. La sélection du curseur à déplacer se fait par proximité (TOUCH_TOLERANCE = 50 px).

### 5.3.6 Mode simulation

Le simulationThread génère des signaux synthétiques (sinus, carré, triangle, ou formule personnalisée) à la même cadence que les données réelles attendues. Ce mode a été utilisé pour valider toutes les fonctionnalités de l'interface de manière indépendante du hardware : trigger, FFT, curseurs, mesures automatiques, zoom tactile. Il constitue un banc de test logiciel complet et a validé le bon fonctionnement de l'ensemble de la chaîne de traitement côté application.

// MainActivity.java — exemple : lecture Bluetooth en Thread private void readDataLoop() {
try {
BufferedReader reader = new BufferedReader( new InputStreamReader(inputStream));

while (isConnected) {
String line = reader.readLine();
if (line != null) {
float value = Float.parseFloat(line.trim()); oscillo.addDataPoint(value); // → OscilloscopeView }
}
} catch (IOException e) {
disconnectBluetooth();
}
}

### 6. Validation du Système

### 6.1 Synthèse de ce qui a été validé

Composant | Type de validation | Résultat
Firmware — DMA/ADC (Nucleo) | Hardware partiel (sans PGA) | OK — buffer circulaire fonctionnel
Firmware — UART Bluetooth | Hardware (HC-05 + terminal) | OK — trames 0xAA/0x55 reçues et vérifiées
Firmware — Endianness | Test fonctionnel sur Nucleo | Bug détecté et corrigé
Protocole — Checksum XOR | Test sur 100 trames consécutives | OK — 0 erreur à 1 m
App Android — Affichage | Mode simulation (tous types) | OK — rendu graphique validé
App Android — FFT 512 pts | Simulation sinus 1 kHz | OK — pic spectral à la bonne fréquence
App Android — Trigger | Simulation sinus et carré | OK — signal stable à l'écran
App Android — Curseurs | Mode simulation | OK — ΔT/ΔV calculés correctement
Chaîne complète BNC→App | Non réalisé (PGA849 manquant) | Non validé
PCB assemblé complet | Non réalisé (composants manquants) | Non validé

### 6.2 Tests firmware sur Nucleo

Le firmware a été testé sur la carte Nucleo-L476RG avec un signal analogique injecté directement sur PA0 depuis un générateur de fonctions, en court-circuitant le PGA849. Les tests ont confirmé le bon fonctionnement du DMA circulaire (alternance HalfCplt/Cplt vérifiée par GPIO toggle sur oscilloscope), la cohérence des valeurs ADC avec le signal injecté (debug UART sur USART2/ST-Link VCP), et la correction du bug de synchronisation DMA après sa détection.

### 6.3 Tests Bluetooth

La liaison HC-05 ↔ application Android a été testée à 1 m, en envoyant des trames DATA simulées depuis le firmware (valeurs générées sans ADC réel). Résultats : 0 erreur checksum sur 100 trames, latence ~90 ms par trame cohérente avec le calcul théorique (1030 octets à 115 200 bps), parsing correct côté application.

### 6.4 Limites de validation

Trois aspects importants n'ont pas pu être validés expérimentalement :
- Précision de mesure de tension avec PGA849 sur toute la plage de gain (×1 à ×200)
- Bande passante réelle du système (objectif 50 kHz, non mesurée)
- Autonomie réelle sur batterie (objectif 6 h, non mesurée)

Ces validations sont directement planifiées pour la suite du projet, dès réception et soudure des composants manquants.

### 7. Difficultés Rencontrées

### 7.1 Retard critique de livraison Mouser

La difficulté principale du projet a été logistique. Le PGA849, commandé sur Mouser, a été livré avec plus de 3 semaines de retard sur la date annoncée. Sans ce composant, l'assemblage de la chaîne d'acquisition complète était impossible. D'autres CMS passifs de précision ont subi des délais similaires.
Cette contrainte nous a forcés à revoir l'organisation du travail : concentration sur le firmware et l'application Android, qui pouvaient progresser indépendamment. Le mode simulation de l'application a alors pris une importance centrale comme outil de validation. En retrospective, commander les composants critiques dès la première semaine du projet avec une marge de sécurité importante aurait évité cette situation.

### 7.2 Bug de synchronisation DMA — ACQ_ClearStatus

Un bug subtil a affecté le firmware pendant plusieurs séances. L'appel à ACQ_ClearStatus() était placé après le traitement des données au lieu de le précéder. En conséquence, un callback DMA pouvait survenir pendant le traitement, le flag était alors écrasé par l'ISR, puis effacé par la boucle principale — et le prochain event DMA était ignoré. L'acquisition fonctionnait mais à la moitié de la fréquence attendue, sans message d'erreur visible.
Le diagnostic a nécessité l'utilisation d'un GPIO en mode toggle pour observer les callbacks ISR sur oscilloscope. La correction (déplacer ACQ_ClearStatus() avant le traitement) était triviale une fois le problème compris.

### 7.3 Problème d'Endianness (Little-Endian STM32 vs Big-Endian Java)

Décrit en détail en section 4.4.2. Ce bug a provoqué des valeurs absurdes côté application lors des premiers tests de communication. Le diagnostic a pris du temps car les données semblaient correctes côté STM32 (vérifiées par UART debug) mais aberrantes côté Android. La prise de conscience de la différence d'endianness entre les deux architectures a orienté vers la solution.

### 7.4 Empreintes KiCad personnalisées

Les empreintes du PGA849 (QFN-16, pas 0,5 mm) et du TSM0515D n'existaient pas dans les bibliothèques standard KiCad. Les modèles trouvés en ligne avaient souvent des dimensions légèrement incorrectes. Elles ont finalement été recréées entièrement à partir des datasheets, en vérifiant chaque cote — un travail fastidieux mais nécessaire pour garantir l'assemblage.

### 7.5 Contraintes de temps et d'organisation

Quatre membres d'équipe avec des emplois du temps différents, des cours en parallèle, des partiels — la coordination n'a pas toujours été simple. La décomposition en modules indépendants (firmware, application, PCB) a aidé à paralléliser le travail, mais les phases d'intégration ont révélé des incompatibilités (endianness, timing) qui auraient pu être anticipées par plus de communication inter-équipe.

### 8. Améliorations et Perspectives

### 8.1 Court terme — Finalisation V1

- Terminer l'assemblage PCB dès réception des composants et valider la chaîne complète.
- Caractériser précision de tension, bande passante et autonomie sur batterie.
- Valider le mode simulation vs acquisition réelle pour calibrer les paramètres d'affichage.

### 8.2 Hardware — V2

- Filtre anti-repliement actif : Sallen-Key 2ème ordre, Fc = 4,5 kHz, avant l'ADC (évite le repliement à Nyquist 5 kHz).
- Seconde voie d'acquisition : ADC2 + second PGA849 pour le mode dual conforme au cahier des charges (mesure de déphasage).
- Mise en forme signal pour TIM3 IC : comparateur à hystérésis LM393 sur PB4 — active la mesure hardware de fréquence (résolution 1 µs vs zero-crossing logiciel).
- LiPo rechargeable + circuit TP4056 : remplacement des piles AA pour un usage plus pratique et rechargeable.
- Augmentation de Fs à 100–200 kHz : oversampling ADC STM32, DMA plus rapide, pour atteindre les 50 kHz de bande passante spécifiés.

### 8.3 Logiciel — V2

- Mode XY (Lissajous) sur l'application quand la 2ème voie sera disponible.
- Export des captures en CSV ou image depuis l'application Android.
- Protocole Bluetooth robustifié : CRC-16 + mécanisme d'ACK/retransmission.
- Auto-calibration du gain dans le firmware (ajustement automatique du PGA en fonction du niveau du signal).

### 9. Conclusion

Ce projet de semestre 6 a été une expérience complète et représentative des réalités du développement d'un système embarqué : bonnes surprises côté logiciel, aléas côté approvisionnement. Le bilan est nuancé, mais loin d'être négatif.
Sur la partie hardware, la conception est aboutie. Le schéma électronique, l'architecture d'alimentation (cascade BU33SD5WG 68 dB PSRR + TSM0515D, protection BAT54S), le PCB double couche ~24 × 95 mm avec isolation analogique/numérique — tout cela représente un travail de conception rigoureux et justifié. Le retard Mouser sur le PGA849 a empêché la validation expérimentale complète, mais la carte est prête à être assemblée et mise en service. Le système est ready-to-plug.

Sur la partie logicielle, le projet est pleinement fonctionnel. Le firmware STM32 (DMA circulaire double buffer, machine à états, protocole Bluetooth avec correction endianness) a été testé et validé sur Nucleo. L'application Android Java — affichage temps réel, FFT 512 points fenêtrée, trigger, curseurs ΔT/ΔV, mesures automatiques, mode simulation — est opérationnelle et a servi de banc de test logiciel pendant tout le développement.
Du point de vue des compétences, ce projet a couvert un spectre remarquablement large : conception schématique, PCB, alimentation analogique, firmware bas niveau (timers, DMA, UART, interruptions), protocoles de communication, et développement mobile Android. C'est précisément l'articulation hardware/software qui définit le métier d'ingénieur en systèmes embarqués, et c'est ce qu'on a appris à maîtriser ici.
La leçon principale à retenir pour un prochain projet : dans tout projet hardware, les délais d'approvisionnement doivent être traités comme un risque de premier ordre. Commander les composants critiques dès la première semaine, avec des marges conservatrices, aurait changé le résultat final. C'est une erreur qu'on ne refera pas.

### Annexes

Annexe A — Bons de commande composants

Fournisseur | Composant / Désignation | Qté | Prix unitaire
Farnell | Commutateur glissière (2435104) | 10 | 0,50 €
Farnell | Diode Zener (1459115) | 5 | 0,15 €
Farnell | Régulateur MCP1826S (1578426) | 1 | 0,79 €
Farnell | Régulateur AP2112K-3.3 (3257429RL) | 5 | 0,22 €
Farnell | Diode Schottky BAT54S | 5 | 0,10 €
Farnell | Condensateur électrolytique 10µF (2466203) | 5 | 0,20 €
Farnell | Convertisseur DC/DC TSM0515D (1205075) | 1 | 9,60 €
Farnell | Support batterie BH4AAW (4305628) | 1 | 3,80 €
Mouser | PGA849RGTR (amplificateur à gain prog.) | 1 | 8,60 €
Mouser | Connecteur coaxial BNC — TE 1478204 | 1 | 3,88 €
Robot-maker | Module Bluetooth HC-05 | 1 | 8,40 €

Annexe B — Configuration STM32CubeMX

Périphérique | Configuration
MCU | STM32L476RGT3 — LQFP-64 — Board NUCLEO-L476RG
SYSCLK | 80 MHz (HSI 16 MHz → PLL ×10 ÷2 via PLLR)

ADC1 | PA0 (IN5), 12 bits, single-ended, Trig = TIM2_TRGO ↑, DMA circulaire
TIM2 | PSC=7, ARR=999, CounterMode=UP, TRGO=UPDATE → 10 kHz
TIM3 | Input Capture CH1 (PB4, AF2), PSC=79 → résolution 1 µs
USART1 | PA9=TX, PA10=RX, 115 200 bps, TX en DMA (Ch4), RX en IT
USART2 | Debug ST-Link VCP, 115 200 bps
DMA1 Ch1 | ADC1 → mémoire, PERIPH_TO_MEM, HALFWORD, circulaire, priorité 1
DMA1 Ch4 | USART1 TX, MEM_TO_PERIPH, BYTE, normal, priorité 2
GPIO PA4/5/6 | Output PP — contrôle gain PGA849 (A0/A1/A2)
GPIO PC13 | Input EXTI falling — bouton B1, anti-rebond 200 ms software

Annexe C — Arborescence du projet firmware

Oscillo V1/
├── Core/
│ | ├── Inc/
│ | │ | ├── acquisition.h | DMA circulaire double buffer
│ | │ | ├── freq_hw.h | TIM3 Input Capture fréquence
│ | │ | ├── freq_measure.h | Zero-crossing fréquence
│ | │ | ├── main.h | Defines globaux, aliases GPIO
│ | │ | ├── pga849.h | Driver PGA849 gain programmable
│ | │ | ├── protocol.h | Protocole 0xAA/0x55, endianness
│ | │ | └── uart_handler.h | UART HC-05, file commandes RX
│ | └── Src/
│ | | ├── acquisition.c | ADC/DMA, callbacks HAL ISR
│ | | ├── freq_hw.c | TIM3 IC, mesure période
│ | | ├── freq_measure.c | Zero-crossing, estimation f
│ | | ├── main.c | Machine à états, boucle principale
│ | | ├── pga849.c | GPIO PA4/5/6, LUT gain
│ | | ├── protocol.c | Build/parse trames, swap endianness
│ | | └── uart_handler.c | TX DMA, RX IT, file FIFO commandes
├── Drivers/
│ | └── STM32L4xx_HAL_Driver/ | HAL ST (non modifiée)
└── Oscillo V1.ioc | Configuration STM32CubeMX 6.15.0

Annexe D — Classes Java application Android

Classe / Interface | Rôle
MainActivity | Activité principale — Bluetooth RFCOMM, simulation, contrôles UI
OscilloscopeView | View personnalisée — rendu signal, FFT, trigger, curseurs, zoom tactile
OnValuesChangeListener | Interface callback OscilloscopeView → MainActivity (gain, timebase...)
BluetoothAdapter | Accès Bluetooth Android (framework)

BluetoothSocket | Connexion RFCOMM au HC-05 via UUID SPP
Thread readDataLoop | Lecture continue InputStream Bluetooth, parsing valeurs flottantes
Thread simulationThread | Génération signaux synthétiques (sin, carré, triangle, formule custom)

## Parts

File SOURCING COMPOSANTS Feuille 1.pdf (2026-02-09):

ACHBAD Younes

BOUDOUX D'HAUTEFEUILLE Gabriel

JABOU Yassine
OZDEN Gökay

PARTIE ALIMENTATION

BATTERIE RECHARGEABLE 3,7V | https://fr.farnell.com/renata/icp582930pr-01/batt-lithium-ion-polymer-3-7v/dp/4312409
REGULATEUR 3,3V | https://fr.farnell.com/diodes-inc/ap2112k-3-3trg1/ldo-fixe-3-3v-0-6a-sot-25-85-c/dp/3257429
COMPOSANT CHARGE USB C | https://fr.farnell.com/microchip/mcp73831t-2dci-ot/chargeur-de-batterie-li-ion-4/dp/1840935
CONNECTEUR USB C | https://fr.farnell.com/gct-global-connector-technology/usb4110-gf-a/conn-usb-2-0-type-c-fem-16-voies/dp/3588206
Connectique batterie femelle | https://fr.farnell.com/jst-japan-solderless-terminals/phr-2/boitier-2-voies-2mm/dp/3616186
Connectique batterie mâle | https://fr.farnell.com/jst-japan-solderless-terminals/b2b-ph-k-s-lf-sn/embase-entree-sup-2-voies/dp/9491856
Commutateur ON/OFF | https://fr.farnell.com/wurth-elektronik/450301014042/commutateur-slide-mini-on-on/dp/2134452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
Transistor de protection | https://fr.farnell.com/onsemi/bss84/transistor-mosfet-canal-p-boitier/dp/1094997
Perle de ferrite ( filtrage analogique ) | https://fr.farnell.com/murata/blm18kg221wh1d/perle-ferrite-aec-q200-220-ohms/dp/3288802
Contact à sertir | https://fr.farnell.com/jst-japan-solderless-terminals/sph-002t-p0-5l/contact-femelle-28-24awg-a-sertir/dp/2399427
Resistance 5,1KOhm | https://fr.farnell.com/bourns/cr0805-fx-5101elf/res-5-1k-1-0-125w-thick-film-0805/dp/4134464
Résistance de charge 2KOhm | https://fr.farnell.com/multicomp-pro/mcwr08x2001ftl/res-couche-epaisse-2k-1-0-125w/dp/2447622
Résistance 100kOhm | https://fr.farnell.com/vishay/crcw0805100kfkta/res-couche-epaisse-100k-1-0-125w/dp/1652905
Résistance de la LED | https://fr.farnell.com/yageo/rc0805fr-07470rp/res-470-ohms-1-0-125w-couche-epaisse/dp/3993423
Condensateur pr MCP | https://fr.farnell.com/kemet/c0805x106k8ractu/condensateur-10-f-10v-10-x7r-0805/dp/2776899
Condensateur régulateur LDO | https://fr.farnell.com/tdk/cga4j3x8r1c105k125ae/cond-aec-q200-1uf-16v-mlcc-0805/dp/3228206
Condensateur découplage | https://fr.farnell.com/multicomp-pro/mc0805b104k101ct/cond-100nf-100v-10-x7r-0805-bobine/dp/2310656
LED verte de Connection | https://fr.farnell.com/multicomp-pro/703-0087/led-vert-3mm-standard/dp/2112096

PARTIE CAPTEUR

buzzer piézo-electrique (alerte sonore) | https://fr.farnell.com/kingstate/kpeg-651san/buzzer-impulsions-rapides/dp/1193660

moniteur de puissance I2C (mesurer la P de l'OK) https://fr.farnell.com/texas-instruments/ina219bidr/current-power-monitor-11khz-soic/dp/3118166

capteur de température (pour voir si l'OK s'emballe )https://fr.farnell.com/nxp/lm75bdp-118/capteur-numerique-tssop-8/dp/2396742

connecteur carte µ-SD ( enregistrer les anomalies et les mesures ) https://fr.farnell.com/molex/104031-0811/connecteur-micro-sd-8pos/dp/2779938

écran OLED 2 broches SDA/SCL | https://fr.farnell.com/midas/mdob128032gv-wi/afficheur-oled-cob-128-x-32-pixels/dp/3407291
connecteur écran/PCB | https://fr.farnell.com/molex/52746-1471/connecteur-fpc-ffc-14-voies-1/dp/1827156

PARTIE CONTROLE DE LA TENSION

Ampli op | https://fr.farnell.com/microchip/mcp601-i-p/ic-cmos-op-amp/dp/1084271
Capa variable | https://fr.farnell.com/c/composants-passifs/condensateurs/condensateurs-variables
Abaisseur de V | https://fr.farnell.com/texas-instruments/ina117p/amp-instrumentation-200khz-pdip8/dp/3004433

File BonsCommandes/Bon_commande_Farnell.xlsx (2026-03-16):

Farnell
Pos | I | P | Art | Désignation | Qté commandée | UA | Date Livraison | Prix unitaire | Devise | Q | Grpe | Div
10 | Z |  |  | COMMUT GLISSIERE SANS C-C 2435104 | 10 | PC | 16.03.26 | 0.5 | EUR | PC | TA.01
20 | Z |  |  | DIODE ZENER 1459115 | 5 | PC | 16.03.26 | 0.149 | EUR | PC | TA.01
30 | Z |  |  | Régu tension MCP1826S 1578426 | 1 | PC | 16.03.26 | 0.79 | EUR | PC | TA.01
40 | Z |  |  | Régu tension AP2112K 3257429RL | 5 | PC | 16.03.26 | 0.218 | EUR | PC | TA.01
50 | Z |  |  | diode schottky | 5 | PC | 16.03.26 | 0.1 | EUR | PC | TA.01
60 | Z |  |  | Condensateur électrolytique alu 2466203 | 5 | PC | 16.03.26 | 0.2 | EUR | PC | TA.01
70 | Z |  |  | Convertisseur DC/DC TSM 0515D 1205075 | 1 | PC | 16.03.26 | 9.6 | EUR | PC | TA.01
80 | Z |  |  | Support de batterie BH4AAW 4305628 | 1 | PC | 16.03.26 | 3.8 | EUR | PC | TA.01

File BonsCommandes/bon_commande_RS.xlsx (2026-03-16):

RS France
Pos | I | P | Art | Désignation | Site | Qté commandée | UA | Date Livraison | Prix unitaire | Devise | Q | Grpe | Div
10 | Z |  |  | Diode Schottky 168-8897 |  | 10 | PC | 18.03.2026 | 0.277 | EUR | PC | TA.01

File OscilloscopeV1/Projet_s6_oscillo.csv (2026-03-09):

Reference | Qty | Value | DNP | Exclude from BOM | Exclude from Board | Footprint | Datasheet
C1,C2,C3,C6,C7,C8,C9,C10,C11,C12 | 10 | 100 nF |  |  |  |  | ~
C4 | 1 | 4.7µ |  |  |  |  | ~
C5 | 1 | 10µ |  |  |  |  | ~
D1 | 1 | BAT54S |  |  |  | Package_TO_SOT_SMD:SOT-23 | https://www.diodes.com/assets/Datasheets/ds11005.pdf
H1,H2,H3,H4 | 4 | MountingHole_Pad |  | Exclure de la Liste du Matériel |  |  | ~
IC1 | 1 | PGA849RGTR |  |  |  | Empreintes:QFN50P300X300X100-17N-D | https://www.ti.com/lit/ds/symlink/pga849.pdf?ts=1751466447660
J1 | 1 | Conn_Coaxial |  |  |  |  | ~
J2 | 1 | Conn_01x06_Socket |  |  |  | Connector_Harwin:Harwin_M20-89006xx_1x06_P2.54mm_Horizontal | ~
J3 | 1 | PILES_3AA |  |  |  |  | ~
J4 | 1 | Conn_01x05_Pin |  |  |  |  | ~
L1 | 1 | 4,7µ |  |  |  |  | ~
PS1 | 1 | TSM_0515D |  |  |  | Empreintes:TSM0515D | https://tracopower.com/tsm-datasheet/
R1,R2,R4 | 3 | 1k |  |  |  |  | ~
R3 | 1 | 9k |  |  |  |  | ~
R5 | 1 | 300 |  |  |  |  | ~
SW1 | 1 | SW_SPST |  |  |  |  | ~
U1 | 1 | MCP6001-OT |  |  |  | Package_TO_SOT_SMD:SOT-23-5 | https://ww1.microchip.com/downloads/en/DeviceDoc/MCP6001-1R-1U-2-4-1-MHz-Low-Power-Op-Amp-DS20001733L.pdf
U2 | 1 | AP2112K-3.3 |  |  |  | Package_TO_SOT_SMD:SOT-23-5 | https://www.diodes.com/assets/Datasheets/AP2112.pdf
U3 | 1 | MCP1640x-xCHY |  |  |  | Package_TO_SOT_SMD:SOT-23-6 | http://ww1.microchip.com/downloads/en/DeviceDoc/20002234D.pdf
U4 | 1 | STM32L476RGTx |  |  |  | Package_QFP:LQFP-64_10x10mm_P0.5mm | https://www.st.com/resource/en/datasheet/stm32l476rg.pdf

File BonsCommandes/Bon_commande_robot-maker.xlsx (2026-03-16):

Robot-maker
Pos | I | P | Art | Désignation | Qté commandée | UA | Date Livraison | Prix unitaire | Devise | Q | Grpe | Div
10 | Z |  |  | Module bluetooth HC-05 | 1 |  |  | 8.4 | EUR | PC | TA.01

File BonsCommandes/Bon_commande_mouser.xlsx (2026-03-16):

Mouser
Pos | I | P | Art | Désignation | Qté commandée | UA | Date Livraison | Prix unitaire | Devise | Q | Grpe | Div
10 | Z |  |  | PGA849 amplificateur | 1 | PC |  | 8.6 | EUR | PC | TA.01
20 | Z |  |  | Connecteurs RF / Connecteurs coaxiaux | 1 | PC |  | 3.88 | EUR | PC | TA.01
Frais de livraison | 20 EUR

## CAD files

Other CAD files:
OscilloscopeV1/Projet_s6_oscillo.step

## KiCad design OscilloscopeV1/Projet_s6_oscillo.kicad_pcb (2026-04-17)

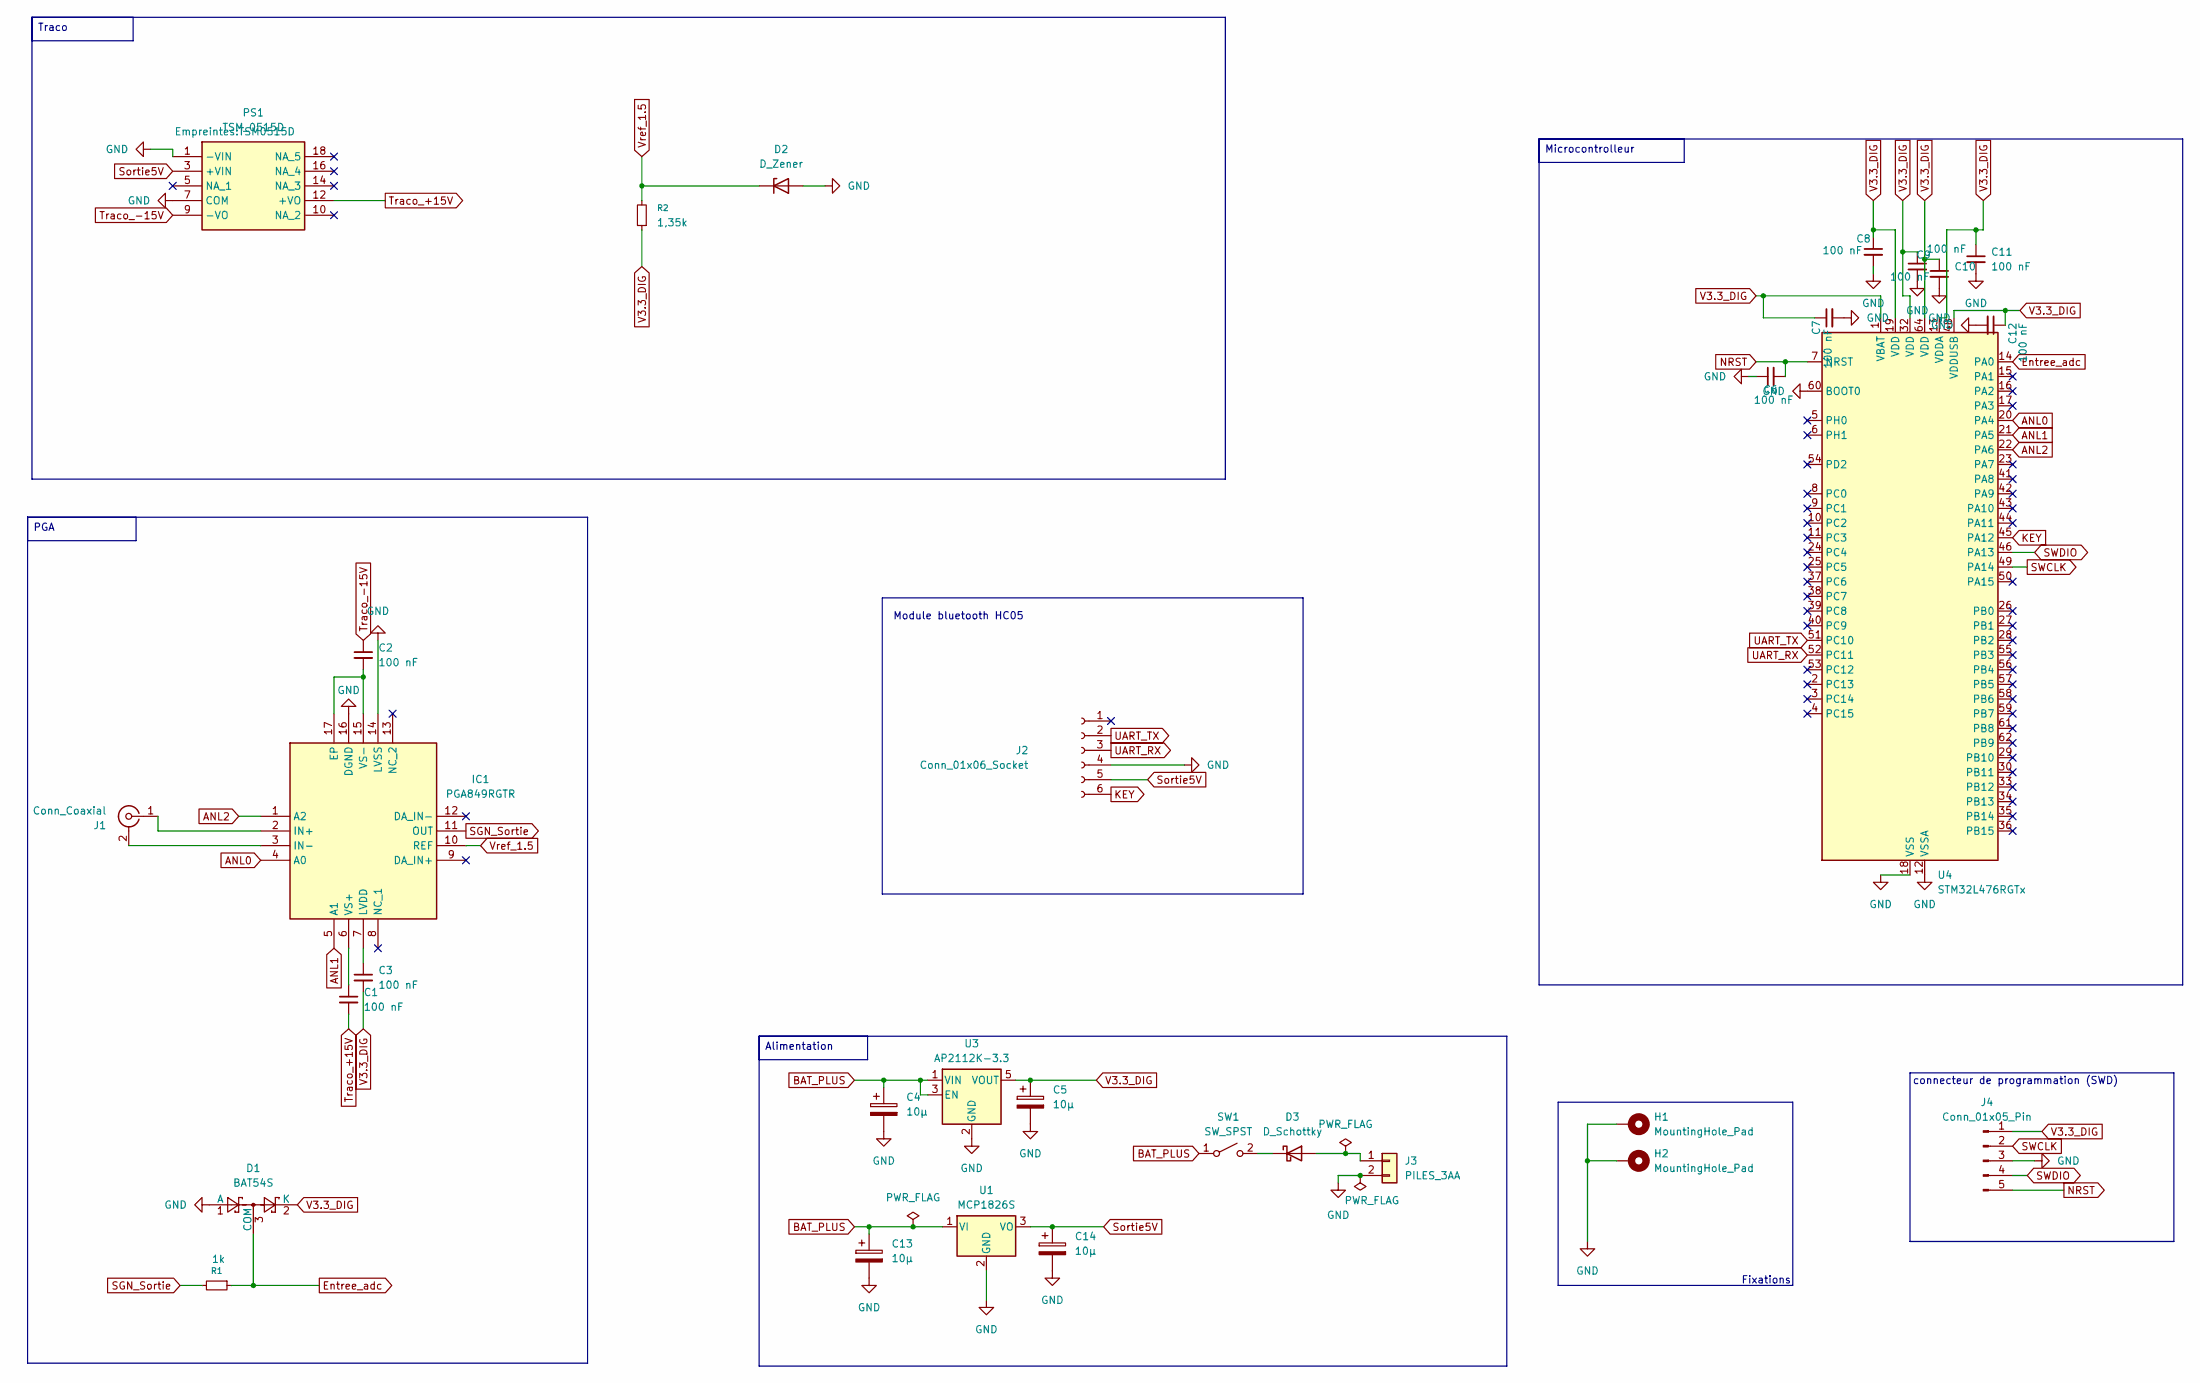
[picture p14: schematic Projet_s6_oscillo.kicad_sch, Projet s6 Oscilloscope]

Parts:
C1, C2, C3, C6, C7, C8, C9, C10, C11, C12: 100 nF; C_0805_2012Metric_Pad1.18x1.45mm_HandSolder
C4, C5, C13, C14: 10µ; CP_Elec_4x5.7
D1: BAT54S; SOT-23
D2: D_Zener; D_SOD-123
D3: D_Schottky; D_SOD-123
H1, H2: MountingHole_Pad; MountingHole_3.2mm_M3_DIN965_Pad
IC1: PGA849RGTR; QFN50P300X300X100-17N-D; Manufacturer_Part_Number PGA849RGTR
J1: Conn_Coaxial; BNC_TEConnectivity_1478204_Vertical
J2: Conn_01x06_Socket; PinSocket_1x06_P2.54mm_Horizontal
J3: PILES_3AA; PinHeader_1x02_P2.54mm_Vertical
J4: Conn_01x05_Pin; PinHeader_1x05_P2.54mm_Vertical
PS1: TSM_0515D; TSM0515D; Manufacturer_Part_Number TSM 0515D; Mouser Part Number 495-TSM-0515D
R1: 1k; R_0805_2012Metric_Pad1.20x1.40mm_HandSolder
R2: 1,35k; R_0815_2038Metric_Pad1.20x4.05mm_HandSolder
SW1: SW_SPST; PinHeader_1x05_P2.54mm_Vertical
U1: MCP1826S; SOT-223
U3: AP2112K-3.3; SOT-23-5
U4: STM32L476RGTx; LQFP-64_10x10mm_P0.5mm

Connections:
ANL0: IC1.4 (A0), U4.20 (PA4)
ANL1: IC1.5 (A1), U4.21 (PA5)
ANL2: IC1.1 (A2), U4.22 (PA6)
BAT_PLUS: C4.1, C13.1, SW1.1 (A), U1.1 (VI), U3.1 (VIN), U3.3 (EN)
Entree_adc: D1.3 (COM), R1.1, U4.14 (PA0)
GND: C4.2, C5.2, C6.1, C7.2, C8.2, C9.2, C10.2, C11.2, C12.2, C13.2, C14.2, D1.1 (A), D2.2 (A), H1.1, H2.1, IC1.14 (LVSS), IC1.16 (DGND), J2.4, J3.2, J4.3, PS1.1 (-VIN), PS1.7 (COM), U1.2 (GND), U3.2 (GND), U4.12 (VSSA), U4.18 (VSS), U4.31 (VSS), U4.47 (VSS), U4.60 (BOOT0), U4.63 (VSS)
KEY: J2.6, U4.45 (PA12)
NRST: C6.2, J4.5, U4.7 (NRST)
unnamed: D3.2 (A), J3.1
unnamed: D3.1 (K), SW1.2 (B)
unnamed: C2.2, IC1.15 (VS-), IC1.17 (EP)
unnamed: IC1.2 (IN+), J1.1 (In)
unnamed: IC1.3 (IN-), J1.2 (Ext)
unnamed: C3.1, IC1.7 (LVDD)
unnamed: C1.1, IC1.6 (VS+)
SGN_Sortie: IC1.11 (OUT), R1.2
SWCLK: J4.2, U4.49 (PA14)
SWDIO: J4.4, U4.46 (PA13)
Sortie5V: C14.1, J2.5, PS1.3 (+VIN), U1.3 (VO)
Traco_+15V: C1.2, PS1.12 (+VO)
Traco_-15V: C2.1, PS1.9 (-VO)
UART_RX: J2.3, U4.52 (PC11)
UART_TX: J2.2, U4.51 (PC10)
V3.3_DIG: C3.2, C5.1, C7.1, C8.1, C9.1, C10.1, C11.1, C12.1, D1.2 (K), J4.1, R2.1, U3.5 (VOUT), U4.1 (VBAT), U4.13 (VDDA), U4.19 (VDD), U4.32 (VDD), U4.48 (VDDUSB), U4.64 (VDD)
Vref_1.5: D2.1 (K), IC1.10 (REF), R2.2

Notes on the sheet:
connecteur de programmation (SWD)
Fixations
Module bluetooth HC05
Traco
PGA
Microcontrolleur
Alimentation

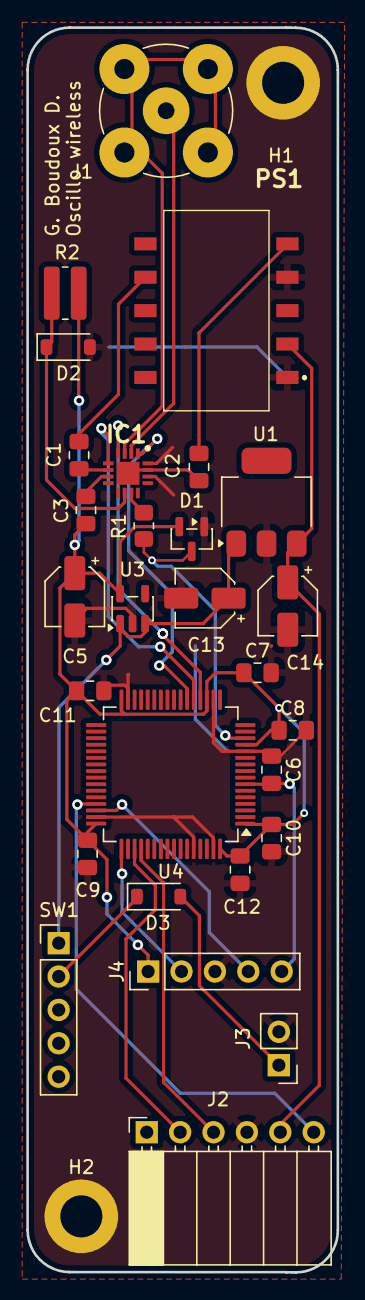
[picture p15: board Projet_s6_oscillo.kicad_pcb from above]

Board: 2 copper layers, 23.6 x 94.7 mm, 30 parts (0 on the bottom side), 25 nets.

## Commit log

2026-02-09 Update ALIMENTATION.md
    Ajout d'explication pour les 2 résistances de 100kOhm
2026-02-16 Ajout de la Librairie des composants
2026-02-16 Addition du schematic partie analogique
    [Projet s6 oscillo.kicad_sch]
2026-02-16 schematic adc v2
    pin for HC05, improvment of pont diviseur
    [Projet s6 oscillo.kicad_sch]
2026-02-16 Partie Alim
    A completer
    [Projet s6 oscilloALIM.kicad_sch]
2026-02-16 Version Presque final du schematics
    [Projet_s6_oscillovpresquefinal.kicad_sch]
2026-02-18 Add files via upload
    c'est juste la partie écran
    [Partie écran.kicad_sch]
2026-02-18 Add files via upload
    Voici la partie bluetooth
    [Oscillo.kicad_sch]
2026-02-18 v4
    Addition of zener instead of op amp for generating 1.5V
    [Projet s6 oscillo.kicad_sch]
2026-03-08 Ajout du connecteur SWD et des fixations
    [Projet_s6_oscillovpresquefinal.kicad_sch]
2026-03-09 Résolution de toutes les erreurs ERC
2026-03-09 Restructuration de l'architecture du projet
    J'ai mis le schéma dans un projet , il est auparavant appart il se trouve désormais dans le dossier Oscillo_Y
    [Oscillo_Y.kicad_pcb, Projet_s6_oscillovpresquefinal.kicad_sch]
2026-03-09 Ajout des Empreintes pour PGA et pour le Traco ( TSM )
2026-03-09 Restructuration des fichiers
    [Oscillo.kicad_sch, Oscillo_Y.kicad_pcb, Projet s6 oscillo.kicad_sch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]
2026-03-09 Ajout du schématique final
    [Projet_s6_oscillovpresquefinal.kicad_pcb, Projet_s6_oscillovpresquefinal.kicad_sch]
2026-03-09 Modification du système d'alimentation / tension de 1,5V
    Modification du système d'alimentation et remplacement du suiveur par une diode zener
    [Projet_s6_oscillovpresquefinal.kicad_sch]
2026-03-09 Ajout de toutes les empreintes
    [Projet_s6_oscillovpresquefinal.kicad_pcb, Projet_s6_oscillovpresquefinal.kicad_sch]
2026-03-09 Finalisation Empreinte
    [Projet_s6_oscillovpresquefinal.kicad_pcb, Projet_s6_oscillovpresquefinal.kicad_sch]
2026-03-09 Avancement PCB
    [Projet_s6_oscillovpresquefinal.kicad_pcb, Projet_s6_oscillovpresquefinal.kicad_sch]
2026-03-16 Avancement PCB : Plans de masse et structuration
    [Projet_s6_oscillovpresquefinal.kicad_pcb, Projet_s6_oscillovpresquefinal.kicad_sch]
2026-03-16 pos mod by A.T.
    pos modifieied by A.T.
    [Bon_commande_Farnell.xlsx, Bon_commande_mouser.xlsx, bon_commande_RS.xlsx]
2026-03-16 Amincissement du pcb
    [Projet_s6_oscillovpresquefinal.kicad_pcb]
2026-03-16 Bon de commande finale
    [Bon_commande_Farnell (1).xlsx, Bon_commande_mouser (1).xlsx, Bon_commande_robot-maker (1).xlsx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]
2026-03-30 Add files via upload
    PCB done the long way
2026-03-30 Start routing (#2)
    * Point de départ du routage
    * Merge pull request #1 from YounesAchb/End-routing
    Add files via upload
    * Add files via upload
    routage du pcb the long way
    * PCB Final
    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
    [Projet_s6_oscillovpresquefinal.kicad_pcb, Projet_s6_oscillovpresquefinal.kicad_sch, Projet_s6_oscillovpresquefinal.step]
2026-03-30 Nettoyage / suppresion fichiers inutiles
    [Bon_commande_Farnell (1).xlsx, Bon_commande_Farnell.xlsx, Bon_commande_mouser (1).xlsx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]
2026-04-16 Add fabrication files
    [Projet_s6_oscillovpresquefinal-B_Cu.gbr, Projet_s6_oscillovpresquefinal-B_Mask.gbr, Projet_s6_oscillovpresquefinal-B_Paste.gbr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]
2026-04-17 fab file add
    [Projet_s6_oscillovpresquefinal.kicad_pcb]
